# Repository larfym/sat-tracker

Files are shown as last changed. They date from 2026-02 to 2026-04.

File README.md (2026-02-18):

# 🛰️ Satellite Tracker

An ESP32-based automated dual-axis antenna tracking system for Low Earth
Orbit (LEO) satellites, featuring real-time orbital prediction,
closed-loop motor control, and a web-based telemetry interface.

------------------------------------------------------------------------

## 📡 Description

**Satellite Tracker** is an embedded platform designed to automatically
track Low Earth Orbit (LEO) satellites in real time using orbital
prediction algorithms.

The system is powered by an ESP32 microcontroller, which:

-   Computes satellite position using the SGP4 orbital propagation model
-   Synchronizes time and geographic location via GPS
-   Controls a motorized offset dish antenna in azimuth and elevation
-   Provides telemetry and configuration through an integrated web
    interface

The platform is modular, scalable, and suitable for experimentation,
amateur satellite tracking, and engineering research.

------------------------------------------------------------------------

## 🚀 Features

-   Real-time satellite tracking using SGP4 orbit prediction
-   Automatic next-pass prediction
-   GPS-based time and position synchronization
-   Integrated web interface for monitoring and configuration
-   JSON API for remote telemetry access
-   Configurable antenna mechanical offsets
-   Satellite visibility calculation (eclipse / daylight / visible)
-   Scalable and modular firmware architecture
-   Manual and automatic tracking modes
-   Dual-axis mount control (azimuth & elevation)
-   Position feedback using reed switches
-   Motor current monitoring for protection and diagnostics
-   PI-based closed-loop position control

------------------------------------------------------------------------

## 📁 Proyect Structure

    sat-tracker/Firmware
    │
    ├── src/                 # Source code
    ├── include/             # Headers y configurations
    ├── data/                # Web Page (SPIFFS / LittleFS)
    ├── lib/                 # Libs
    ├── platformio.ini       # PlatformIO config.

------------------------------------------------------------------------

## 🔧 Hardware Requirements

-   ESP32 DevKit V1
-   GPS Module
-   Custom Power Interface Board
-   Custom Main Control Board
-   Azimuth and Elevation actuators
-   36V / 5A power supply

------------------------------------------------------------------------

## 💻 Software Dependencies

-   SGP4 -- Satellite orbit prediction\
    https://github.com/Hopperpop/Sgp4-Library

-   ESPAsyncWebServer -- Asynchronous web server\
    https://github.com/me-no-dev/ESPAsyncWebServer

-   TinyGPS++ -- GPS NMEA parsing\
    https://github.com/mikalhart/TinyGPSPlus

-   ArduinoJson -- JSON serialization and parsing\
    https://arduinojson.org/

All dependencies are automatically managed via PlatformIO.

------------------------------------------------------------------------

## 🛠 Building and Installation

1.  Clone this repository:

git clone https://github.com/larfym/sat-tracker.git

2.  Install PlatformIO: https://platformio.org/

3.  Open the Firmware folder in VS Code with the PlatformIO extension.

4.  Build and upload:

platformio run --target uploadfs platformio run --target upload

------------------------------------------------------------------------

## 🌐 Web Interface

To access the web interface:

1.  Connect to the ESP32 WiFi Access Point (Default SSID: SatTracker)
2.  Open your browser and navigate to:

http://tracker.local

From the web interface you can:

-   Configure satellite TLE data
-   Adjust antenna offsets
-   Monitor real-time telemetry
-   Switch between manual and automatic tracking
-   View GPS and system status
-   Monitor next pass prediction

## 📜 License

This project is licensed under the GNU General Public License v3.0 - see [LICENSE](LICENSE) for details.

------------------------------------------------------------------------

🛰 Satellite Tracker -- Embedded autonomous satellite tracking platform.

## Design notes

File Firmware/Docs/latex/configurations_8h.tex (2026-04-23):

\doxysection{include/\+configurations.h File Reference}
\hypertarget{configurations_8h}{}\label{configurations_8h}\index{include/configurations.h@{include/configurations.h}}
{\ttfamily \+\#include $<$Arduino.\+h$>$}\newline
{\ttfamily \+\#include "{}driver/\+gpio.\+h"{}}\newline
\doxysubsubsection*{Macros}
\begin{DoxyCompactItemize}
\item 
\+\#define \doxymbox{\hyperlink{configurations_8h_a56e165627f596c2f42f843ae6571de0e}{PWM\+\_\+\+FREQ\+\_\+\+HZ}}~2500
\begin{DoxyCompactList}\small\item\em PWM frequency for PWM motor speed control (Hz). \end{DoxyCompactList}\end{DoxyCompactItemize}
\begin{Indent}\textbf{ Azimuth Motor Pins (AZ)}\par
{\em Control and measurement pins for the Azimuth motor driver. }\begin{DoxyCompactItemize}
\item 
\+\#define \doxymbox{\hyperlink{configurations_8h_a9ce983ce5b08d7846d8fa31118021b24}{IN1\+\_\+\+AZ\+\_\+\+PIN}}~GPIO\+\_\+\+NUM\+\_\+25
\item 
\+\#define \doxymbox{\hyperlink{configurations_8h_ab18abfaf88f25a5ba352779defd5b333}{EN\+\_\+\+AZ\+\_\+\+PIN}}~GPIO\+\_\+\+NUM\+\_\+12
\item 
\+\#define \doxymbox{\hyperlink{configurations_8h_a9d57a6e7ffc17486374ef9dc813b76f4}{IN2\+\_\+\+AZ\+\_\+\+PIN}}~GPIO\+\_\+\+NUM\+\_\+26
\item 
\+\#define \doxymbox{\hyperlink{configurations_8h_ab1858222d0c9bde8f3a6dc0bfd6c6602}{I\+\_\+\+AZ\+\_\+\+PIN}}~GPIO\+\_\+\+NUM\+\_\+36
\item 
\+\#define \doxymbox{\hyperlink{configurations_8h_a4c9747a154da64ff447148d8d4fa5a20}{I\+\_\+\+AZ\+\_\+\+CHANNEL}}~ADC1\+\_\+\+CHANNEL\+\_\+0
\end{DoxyCompactItemize}
\end{Indent}
\begin{Indent}\textbf{ Elevation Motor Pins (EL)}\par
{\em Control and measurement pins for the Elevation motor driver. }\begin{DoxyCompactItemize}
\item 
\+\#define \doxymbox{\hyperlink{configurations_8h_a2f5dd98516c40e68c6da603ddcab8698}{IN1\+\_\+\+EL\+\_\+\+PIN}}~GPIO\+\_\+\+NUM\+\_\+27
\item 
\+\#define \doxymbox{\hyperlink{configurations_8h_a48348f346a55b4cdd6249e8d8491242d}{EN\+\_\+\+EL\+\_\+\+PIN}}~GPIO\+\_\+\+NUM\+\_\+13
\item 
\+\#define \doxymbox{\hyperlink{configurations_8h_a3c8358b42b349a816f9ef990377fd98b}{IN2\+\_\+\+EL\+\_\+\+PIN}}~GPIO\+\_\+\+NUM\+\_\+14
\item 
\+\#define \doxymbox{\hyperlink{configurations_8h_aad16931d726a00fa1f731f95541eef10}{I\+\_\+\+EL\+\_\+\+PIN}}~GPIO\+\_\+\+NUM\+\_\+39
\item 
\+\#define \doxymbox{\hyperlink{configurations_8h_a879a26029e799249e6786c5890d9f7e1}{I\+\_\+\+EL\+\_\+\+CHANNEL}}~ADC1\+\_\+\+CHANNEL\+\_\+3
\end{DoxyCompactItemize}
\end{Indent}
\begin{Indent}\textbf{ Communication \& Sensor Pins}\par
{\em Pins for external modules (GPS) and reed switch. }\begin{DoxyCompactItemize}
\item 
\+\#define \doxymbox{\hyperlink{configurations_8h_a6f8927970de9eedcbb8f6c14b1d0d6c3}{GPS\+\_\+\+RX\+\_\+\+PIN}}~16
\item 
\+\#define \doxymbox{\hyperlink{configurations_8h_acae14b9c1767cfec367a4b96009c94e5}{GPS\+\_\+\+TX\+\_\+\+PIN}}~17
\item 
\+\#define \doxymbox{\hyperlink{configurations_8h_aa87d687897e717dea73184063e2b3be1}{REED\+\_\+\+AZ\+\_\+\+PIN}}~GPIO\+\_\+\+NUM\+\_\+22
\item 
\+\#define \doxymbox{\hyperlink{configurations_8h_ac623bf5b9b1b5e841f3d5358f5ce36f7}{REED\+\_\+\+EL\+\_\+\+PIN}}~GPIO\+\_\+\+NUM\+\_\+23
\end{DoxyCompactItemize}
\end{Indent}
\begin{Indent}\textbf{ Antenna Mount Dimensions}\par
{\em Geometric parameters of the antenna mount for non-\/linearity compensation.

\begin{DoxyNote}{Note}
See ./\+\+Hardware/\+\+Dimensiones.png for reference. All dimensions are in millimeters. 
\end{DoxyNote}
}\begin{DoxyCompactItemize}
\item 
\+\#define \doxymbox{\hyperlink{configurations_8h_a39a4aef518070719f955536fb18f6636}{A\+\_\+\+ANT}}~50.\+0f
\item 
\+\#define \doxymbox{\hyperlink{configurations_8h_a034c4b2e2cf4a02e546516bea24d038b}{BP\+\_\+\+ANT}}~220.\+11f
\item 
\+\#define \doxymbox{\hyperlink{configurations_8h_a149b23fbb2b8ad13b0ad21dbecd1059a}{C\+\_\+\+ANT}}~276.\+00f
\item 
\+\#define \doxymbox{\hyperlink{configurations_8h_a2ac51fcc017948d66c75b95473b426c4}{D\+\_\+\+ANT}}~145.\+0f
\item 
\+\#define \doxymbox{\hyperlink{configurations_8h_aed5df61912c8c1b1f45d597496d14625}{E\+\_\+\+ANT}}~80.\+0f
\item 
\+\#define \doxymbox{\hyperlink{configurations_8h_accf0d3a1b60705451b9e5a78e37f82c5}{F\+\_\+\+ANT}}~258.\+00f
\end{DoxyCompactItemize}
\end{Indent}
\begin{Indent}\textbf{ Wi\+Fi Configuration}\par
{\em Default parameters for Wi\+Fi access point and m\+DNS service. }\begin{DoxyCompactItemize}
\item 
\+\#define \doxymbox{\hyperlink{configurations_8h_a7ea92631acc3bc41ae5eadc069323267}{DEFAULT\+\_\+\+WIFI\+\_\+\+SSID}}~"{}Tracker\+LARFy\+M"{}
\item 
\+\#define \doxymbox{\hyperlink{configurations_8h_a151690ecdd7d2c7b69586e6df164676c}{DEFAULT\+\_\+\+WIFI\+\_\+\+PASSWORD}}~"{}"{}
\item 
\+\#define \doxymbox{\hyperlink{configurations_8h_af257e2a3e091629829857a2eb8931a7a}{DEFAULT\+\_\+\+SERVER\+\_\+\+PORT}}~80
\item 
\+\#define \doxymbox{\hyperlink{configurations_8h_a2597be4e15dcb4d93d323730f9ac2838}{MDNS\+\_\+\+SERVICE\+\_\+\+NAME}}~"{}Tracker"{}
\end{DoxyCompactItemize}
\end{Indent}
\begin{Indent}\textbf{ Serial Debugging}\par
{\em Default serial monitor parameters. }\begin{DoxyCompactItemize}
\item 
\+\#define \doxymbox{\hyperlink{configurations_8h_a89f82a9d44beaa52b00c7245a50a105c}{SERIAL\+\_\+\+BAUDRATE}}~115200
\end{DoxyCompactItemize}
\end{Indent}
\begin{Indent}\textbf{ GPS Parameters}\par
{\em UART settings and default fallback position/\+time. }\begin{DoxyCompactItemize}
\item 
\+\#define \doxymbox{\hyperlink{configurations_8h_a0276fa67794ae64b565fe0da6db4fc9d}{GPS\+\_\+\+UART}}~1
\item 
\+\#define \doxymbox{\hyperlink{configurations_8h_ac81ef7244c62ee5ea3a9a637a07ac921}{GPS\+\_\+\+BAUDRATE}}~9600
\end{DoxyCompactItemize}
\end{Indent}
\begin{Indent}\textbf{ DC Motor Configuration.}\par
{\em Non Linearity \& Nominal Tension (Saturation) }\begin{DoxyCompactItemize}
\item 
\+\#define \doxymbox{\hyperlink{configurations_8h_a114551a5238cb0c6d988e55ba1d563c1}{M\+\_\+\+V\+\_\+\+NOMINAL}}~36
\item 
\+\#define \doxymbox{\hyperlink{configurations_8h_af612d680313c8e405272d106245d0fe6}{M\+\_\+\+AZ\+\_\+\+V\+\_\+\+TO\+\_\+\+START}}~15.\+5
\item 
\+\#define \doxymbox{\hyperlink{configurations_8h_afd517c26a46c866b3e18cf00c0e9b24b}{M\+\_\+\+EL\+\_\+\+V\+\_\+\+TO\+\_\+\+START}}~9
\item 
\+\#define \doxymbox{\hyperlink{configurations_8h_adf6dcd893480852d7a468e561027c267}{M\+\_\+\+STOP\+\_\+\+DUTY}}~25
\item 
\+\#define \doxymbox{\hyperlink{configurations_8h_ac37c3874949285db365830a0af9ba6f0}{M\+\_\+\+MAX\+\_\+\+DUTY}}~100
\item 
\+\#define \doxymbox{\hyperlink{configurations_8h_aa9fc601eb8b6247f0e9a63ba560190d0}{M\+\_\+\+AZ\+\_\+\+SETTLING\+\_\+\+TIME\+\_\+\+MS}}~65
\item 
\+\#define \doxymbox{\hyperlink{configurations_8h_aa2ff7abced059abb3e126b9e24d8b31a}{M\+\_\+\+EL\+\_\+\+SETTLING\+\_\+\+TIME\+\_\+\+MS}}~100
\item 
\+\#define \doxymbox{\hyperlink{configurations_8h_aa33b361d28f2f88e6bfd400a945594f5}{M\+\_\+\+STOPPED\+\_\+\+CHECK\+\_\+\+INTERVAL\+\_\+\+MS}}~10
\end{DoxyCompactItemize}
\end{Indent}
\begin{Indent}\textbf{ Actuator pulses resolution}\par
{\em Resolution per pulses of reed. }\begin{DoxyCompactItemize}
\item 
\+\#define \doxymbox{\hyperlink{configurations_8h_a618a262e13ca80c7900729cce273a2ac}{AZIMUTH\+\_\+\+RESOLUTION\+\_\+angle}}~0.\+225
\item 
\+\#define \doxymbox{\hyperlink{configurations_8h_a391fdd14353e44f4001f8754e497dbec}{ELEVATION\+\_\+\+RESOLUTION\+\_\+mm}}~0.\+8
\end{DoxyCompactItemize}
\end{Indent}
\begin{Indent}\textbf{ Motor Current Limits}\par
{\em Safety current limits for motor protection. }\begin{DoxyCompactItemize}
\item 
\+\#define \doxymbox{\hyperlink{configurations_8h_a53f290d4e302a2bc20466bea8c913956}{CURRENT\+\_\+\+AZIMUTH\+\_\+\+MAX\+\_\+mA}}~1000.\+0
\item 
\+\#define \doxymbox{\hyperlink{configurations_8h_a23704dd1aa5111b43de738b89232a9e2}{CURRENT\+\_\+\+ELEVATION\+\_\+\+MAX\+\_\+mA}}~1000.\+0
\item 
\+\#define \doxymbox{\hyperlink{configurations_8h_ada73a694caa3cc91084dd186c39d41e1}{CURRENT\+\_\+\+HOMING\+\_\+mA}}~10.\+0
\end{DoxyCompactItemize}
\end{Indent}
\begin{Indent}\textbf{ Timing Parameters}\par
{\em Control-\/loop timing settings. }\begin{DoxyCompactItemize}
\item 
\+\#define \doxymbox{\hyperlink{configurations_8h_ab51c362d04fd48de5e648831613ceb9b}{TIMER\+\_\+\+PREESCALER}}~80
\item 
\+\#define \doxymbox{\hyperlink{configurations_8h_a4b801f5bec6966fa50dbca2c4fd789eb}{DEFAULT\+\_\+\+SAMPLE\+\_\+\+TIME\+\_\+\+US}}~500
\item 
\+\#define \doxymbox{\hyperlink{configurations_8h_a71e747b23aad740159d5c63f2d28f097}{SAMPLE\+\_\+\+TIME\+\_\+\+US}}~500
\item 
\+\#define \doxymbox{\hyperlink{configurations_8h_a048e4fab329b80f602ac97b6aed12979}{SAMPLE\+\_\+\+TIME\+\_\+S}}~(\doxymbox{\hyperlink{configurations_8h_a71e747b23aad740159d5c63f2d28f097}{SAMPLE\+\_\+\+TIME\+\_\+\+US}} /\+ 1000000.\+0)
\item 
\+\#define \doxymbox{\hyperlink{configurations_8h_a3e0f664cc702c0239f5996a93e2e61de}{SAMPLE\+\_\+\+TIME\+\_\+\+SGP4\+\_\+\+MS}}~50
\end{DoxyCompactItemize}
\end{Indent}
\begin{Indent}\textbf{ PID Gains — Azimuth}\par
{\em Gains for the Azimuth axis PI controller. }\begin{DoxyCompactItemize}
\item 
\+\#define \doxymbox{\hyperlink{configurations_8h_aeb86acb27e54b9755fcdac7881be9a67}{KP\+\_\+\+AZIMUTH}}~10.\+0
\item 
\+\#define \doxymbox{\hyperlink{configurations_8h_a84c8a48add65471b6d7a3df86ded588a}{KI\+\_\+\+AZIMUTH}}~1
\end{DoxyCompactItemize}
\end{Indent}
\begin{Indent}\textbf{ PID Gains — Elevation}\par
{\em Gains for the Elevation axis PI controller. }\begin{DoxyCompactItemize}
\item 
\+\#define \doxymbox{\hyperlink{configurations_8h_aa837cea21a670725c8482e7379c50b84}{KP\+\_\+\+ELEVATION}}~7.\+0
\item 
\+\#define \doxymbox{\hyperlink{configurations_8h_a9f3f39cf87464e2b698790a8d22894d4}{KI\+\_\+\+ELEVATION}}~0.\+5
\end{DoxyCompactItemize}
\end{Indent}
\begin{Indent}\textbf{ Soft Limit Positions}\par
{\em Encoder/\+step limits for mechanical range enforcement. }\begin{DoxyCompactItemize}
\item 
\+\#define \doxymbox{\hyperlink{configurations_8h_a9fc5bef92112470db8255986b6ecebcb}{REED\+\_\+\+AZ\+\_\+\+SOFT\+\_\+\+LIMIT\+\_\+\+HIGH}}~1610
\item 
\+\#define \doxymbox{\hyperlink{configurations_8h_a7de64bbb117e66e561add80d7f24374e}{REED\+\_\+\+EL\+\_\+\+SOFT\+\_\+\+LIMIT\+\_\+\+HIGH}}~435
\item 
\+\#define \doxymbox{\hyperlink{configurations_8h_acdaca90d9569b370599f231928e32845}{REED\+\_\+\+AZ\+\_\+\+SOFT\+\_\+\+LIMIT\+\_\+\+LOW}}~-\/5
\item 
\+\#define \doxymbox{\hyperlink{configurations_8h_a08a68068b1a658d3b0e967b799a84100}{REED\+\_\+\+EL\+\_\+\+SOFT\+\_\+\+LIMIT\+\_\+\+LOW}}~-\/5
\end{DoxyCompactItemize}
\end{Indent}
\begin{Indent}\textbf{ Hardware Limit Positions}\par
\begin{DoxyCompactItemize}
\item 
\+\#define \doxymbox{\hyperlink{configurations_8h_ad23baeb01d87433d396f0fe003b8786d}{EL\+\_\+\+MIN\+\_\+\+DEG}}~0
\item 
\+\#define \doxymbox{\hyperlink{configurations_8h_a256d7fdd4d6568904b4d60a6764b3fd1}{EL\+\_\+\+MAX\+\_\+\+DEG}}~90
\item 
\+\#define \doxymbox{\hyperlink{configurations_8h_aa9c6275c5b158a9c5367abcc0a1a51d1}{AZ\+\_\+\+MIN\+\_\+\+DEG}}~0
\item 
\+\#define \doxymbox{\hyperlink{configurations_8h_a9ca2a700dc3c9463ffec3c3e49d919d1}{AZ\+\_\+\+MAX\+\_\+\+DEG}}~340
\end{DoxyCompactItemize}
\end{Indent}
\begin{Indent}\textbf{ Current signal Adaptation}\par
{\em gain \& shunt value }\begin{DoxyCompactItemize}
\item 
\+\#define \doxymbox{\hyperlink{configurations_8h_aa25a725425da550762ed5792cf0a1b65}{SHUNT\+\_\+\+AZ\+\_\+\+OHM}}~0.\+3333333
\item 
\+\#define \doxymbox{\hyperlink{configurations_8h_ab363ea10e9d0da7012f8f6cbdcee7882}{CURRENT\+\_\+\+GAIN\+\_\+\+AZ}}~2.\+11988
\item 
\+\#define \doxymbox{\hyperlink{configurations_8h_afd090c34883b15dab99c6ff746a4af76}{SHUNT\+\_\+\+EL\+\_\+\+OHM}}~0.\+09
\item 
\+\#define \doxymbox{\hyperlink{configurations_8h_a62b33caa3a185c31056a204f70eba631}{CURRENT\+\_\+\+GAIN\+\_\+\+EL}}~7.\+07773
\item 
\+\#define \doxymbox{\hyperlink{configurations_8h_a8a4220fddcc006052f5142591343b76b}{ADC\+\_\+\+MEASURE\+\_\+\+SAMPLES}}~128
\end{DoxyCompactItemize}
\end{Indent}
\begin{Indent}\textbf{ Task Priorities}\par
{\em Priorities for Free\+RTOS tasks (0 = lowest priority). }\begin{DoxyCompactItemize}
\item 
\+\#define \doxymbox{\hyperlink{configurations_8h_a6a03ad7d94899986123153626e22f20e}{TASK\+\_\+\+STOP\+\_\+\+MOTION\+\_\+\+PRIORITY}}~17
\item 
\+\#define \doxymbox{\hyperlink{configurations_8h_a6b00c9b90fcc5568a4740fca93e954b3}{TASK\+\_\+\+HOME\+\_\+\+PRIORITY}}~16
\item 
\+\#define \doxymbox{\hyperlink{configurations_8h_abe8130df0295957593947f186524a786}{TASK\+\_\+\+GPS\+\_\+\+PRIORITY}}~15
\item 
\+\#define \doxymbox{\hyperlink{configurations_8h_af85d4f2634be8dc9a6bd6255f1f8688e}{TASK\+\_\+\+TRACKING\+\_\+\+CALCULATION\+\_\+\+PRIORITY}}~14
\item 
\+\#define \doxymbox{\hyperlink{configurations_8h_a3887054e089a66a41ada671027994436}{TASK\+\_\+\+MOTION\+\_\+\+CONTROL\+\_\+\+PRIORITY}}~14
\item 
\+\#define \doxymbox{\hyperlink{configurations_8h_ac438e71fd931e96cd5d66b3a30630ad9}{TASK\+\_\+\+CURRENT\+\_\+\+MONITOR\+\_\+\+PRIORITY}}~12
\item 
\+\#define \doxymbox{\hyperlink{configurations_8h_a8d137660d77a1310d990d0616a8c2b48}{TASK\+\_\+\+TELEMETRY\+\_\+\+PRIORITY}}~11
\end{DoxyCompactItemize}
\end{Indent}
\begin{Indent}\textbf{ Task Timing Parameters}\par
{\em Timing parameters for Free\+RTOS tasks (in milliseconds). }\begin{DoxyCompactItemize}
\item 
\+\#define \doxymbox{\hyperlink{configurations_8h_a7f179f9e3432a2afae54c63142143cba}{TASK\+\_\+\+LOOP\+\_\+\+DELAY}}~1000
\item 
\+\#define \doxymbox{\hyperlink{configurations_8h_a49fd20d40240fe22eaf939ab4d7f0ead}{TASK\+\_\+\+GPS\+\_\+\+DELAY}}~1000
\item 
\+\#define \doxymbox{\hyperlink{configurations_8h_a21b4e7669d6c855ecc63462be14d163e}{TASK\+\_\+\+CURRENT\+\_\+\+MONITOR\+\_\+\+DELAY}}~3000
\item 
\+\#define \doxymbox{\hyperlink{configurations_8h_a34f3c557893c6a9c133f63f9f3647669}{TASK\+\_\+\+HOME\+\_\+\+CURRENT\+\_\+\+DELAY}}~200
\item 
\+\#define \doxymbox{\hyperlink{configurations_8h_ae38a7f5e2f24d06689d8b847a35e5ccf}{TASK\+\_\+\+TELEMETRY\+\_\+\+DELAY}}~1000
\end{DoxyCompactItemize}
\end{Indent}
\begin{Indent}\textbf{ Task Stack Sizes}\par
{\em Stack sizes for Free\+RTOS tasks (in bytes). }\begin{DoxyCompactItemize}
\item 
\+\#define \doxymbox{\hyperlink{configurations_8h_accbb358028675c83675d8b34c386268d}{MAX\+\_\+\+STACK\+\_\+\+SIZE}}~8192
\item 
\+\#define \doxymbox{\hyperlink{configurations_8h_a214a51a36ae692b76f900157fbd5148d}{MEDIUM\+\_\+\+STACK\+\_\+\+SIZE}}~2048
\item 
\+\#define \doxymbox{\hyperlink{configurations_8h_ac9a8e754ddaa2697e9e675579912a15f}{MIN\+\_\+\+STACK\+\_\+\+SIZE}}~1024
\end{DoxyCompactItemize}
\end{Indent}

\label{doc-define-members}
\Hypertarget{configurations_8h_doc-define-members}
\doxysubsection{Macro Definition Documentation}
\Hypertarget{configurations_8h_a39a4aef518070719f955536fb18f6636}\index{configurations.h@{configurations.h}!A\_ANT@{A\_ANT}}
\index{A\_ANT@{A\_ANT}!configurations.h@{configurations.h}}
\doxysubsubsection{\texorpdfstring{A\_ANT}{A\_ANT}}
{\footnotesize\ttfamily \label{configurations_8h_a39a4aef518070719f955536fb18f6636} 
\+\#define A\+\_\+\+ANT~50.\+0f}

\Hypertarget{configurations_8h_a8a4220fddcc006052f5142591343b76b}\index{configurations.h@{configurations.h}!ADC\_MEASURE\_SAMPLES@{ADC\_MEASURE\_SAMPLES}}
\index{ADC\_MEASURE\_SAMPLES@{ADC\_MEASURE\_SAMPLES}!configurations.h@{configurations.h}}
\doxysubsubsection{\texorpdfstring{ADC\_MEASURE\_SAMPLES}{ADC\_MEASURE\_SAMPLES}}
{\footnotesize\ttfamily \label{configurations_8h_a8a4220fddcc006052f5142591343b76b} 
\+\#define ADC\+\_\+\+MEASURE\+\_\+\+SAMPLES~128}

Number of samples to take for averaging during measurement. \Hypertarget{configurations_8h_a9ca2a700dc3c9463ffec3c3e49d919d1}\index{configurations.h@{configurations.h}!AZ\_MAX\_DEG@{AZ\_MAX\_DEG}}
\index{AZ\_MAX\_DEG@{AZ\_MAX\_DEG}!configurations.h@{configurations.h}}
\doxysubsubsection{\texorpdfstring{AZ\_MAX\_DEG}{AZ\_MAX\_DEG}}
{\footnotesize\ttfamily \label{configurations_8h_a9ca2a700dc3c9463ffec3c3e49d919d1} 
\+\#define AZ\+\_\+\+MAX\+\_\+\+DEG~340}

Upper Set\+Point limit for Azimuth. \Hypertarget{configurations_8h_aa9c6275c5b158a9c5367abcc0a1a51d1}\index{configurations.h@{configurations.h}!AZ\_MIN\_DEG@{AZ\_MIN\_DEG}}
\index{AZ\_MIN\_DEG@{AZ\_MIN\_DEG}!configurations.h@{configurations.h}}
\doxysubsubsection{\texorpdfstring{AZ\_MIN\_DEG}{AZ\_MIN\_DEG}}
{\footnotesize\ttfamily \label{configurations_8h_aa9c6275c5b158a9c5367abcc0a1a51d1} 
\+\#define AZ\+\_\+\+MIN\+\_\+\+DEG~0}

Lower Set\+Point limit for Azimuth. \Hypertarget{configurations_8h_a618a262e13ca80c7900729cce273a2ac}\index{configurations.h@{configurations.h}!AZIMUTH\_RESOLUTION\_angle@{AZIMUTH\_RESOLUTION\_angle}}
\index{AZIMUTH\_RESOLUTION\_angle@{AZIMUTH\_RESOLUTION\_angle}!configurations.h@{configurations.h}}
\doxysubsubsection{\texorpdfstring{AZIMUTH\_RESOLUTION\_angle}{AZIMUTH\_RESOLUTION\_angle}}
{\footnotesize\ttfamily \label{configurations_8h_a618a262e13ca80c7900729cce273a2ac} 
\+\#define AZIMUTH\+\_\+\+RESOLUTION\+\_\+angle~0.\+225}

Degrees per reed pulse for Azimuth. \Hypertarget{configurations_8h_a034c4b2e2cf4a02e546516bea24d038b}\index{configurations.h@{configurations.h}!BP\_ANT@{BP\_ANT}}
\index{BP\_ANT@{BP\_ANT}!configurations.h@{configurations.h}}
\doxysubsubsection{\texorpdfstring{BP\_ANT}{BP\_ANT}}
{\footnotesize\ttfamily \label{configurations_8h_a034c4b2e2cf4a02e546516bea24d038b} 
\+\#define BP\+\_\+\+ANT~220.\+11f}

\Hypertarget{configurations_8h_a149b23fbb2b8ad13b0ad21dbecd1059a}\index{configurations.h@{configurations.h}!C\_ANT@{C\_ANT}}
\index{C\_ANT@{C\_ANT}!configurations.h@{configurations.h}}
\doxysubsubsection{\texorpdfstring{C\_ANT}{C\_ANT}}
{\footnotesize\ttfamily \label{configurations_8h_a149b23fbb2b8ad13b0ad21dbecd1059a} 
\+\#define C\+\_\+\+ANT~276.\+00f}

\Hypertarget{configurations_8h_a53f290d4e302a2bc20466bea8c913956}\index{configurations.h@{configurations.h}!CURRENT\_AZIMUTH\_MAX\_mA@{CURRENT\_AZIMUTH\_MAX\_mA}}
\index{CURRENT\_AZIMUTH\_MAX\_mA@{CURRENT\_AZIMUTH\_MAX\_mA}!configurations.h@{configurations.h}}
\doxysubsubsection{\texorpdfstring{CURRENT\_AZIMUTH\_MAX\_mA}{CURRENT\_AZIMUTH\_MAX\_mA}}
{\footnotesize\ttfamily \label{configurations_8h_a53f290d4e302a2bc20466bea8c913956} 
\+\#define CURRENT\+\_\+\+AZIMUTH\+\_\+\+MAX\+\_\+mA~1000.\+0}

Max DC current for Azimuth motor (mA). \Hypertarget{configurations_8h_a23704dd1aa5111b43de738b89232a9e2}\index{configurations.h@{configurations.h}!CURRENT\_ELEVATION\_MAX\_mA@{CURRENT\_ELEVATION\_MAX\_mA}}
\index{CURRENT\_ELEVATION\_MAX\_mA@{CURRENT\_ELEVATION\_MAX\_mA}!configurations.h@{configurations.h}}
\doxysubsubsection{\texorpdfstring{CURRENT\_ELEVATION\_MAX\_mA}{CURRENT\_ELEVATION\_MAX\_mA}}
{\footnotesize\ttfamily \label{configurations_8h_a23704dd1aa5111b43de738b89232a9e2} 
\+\#define CURRENT\+\_\+\+ELEVATION\+\_\+\+MAX\+\_\+mA~1000.\+0}

Max DC current for Elevation motor (mA). \Hypertarget{configurations_8h_ab363ea10e9d0da7012f8f6cbdcee7882}\index{configurations.h@{configurations.h}!CURRENT\_GAIN\_AZ@{CURRENT\_GAIN\_AZ}}
\index{CURRENT\_GAIN\_AZ@{CURRENT\_GAIN\_AZ}!configurations.h@{configurations.h}}
\doxysubsubsection{\texorpdfstring{CURRENT\_GAIN\_AZ}{CURRENT\_GAIN\_AZ}}
{\footnotesize\ttfamily \label{configurations_8h_ab363ea10e9d0da7012f8f6cbdcee7882} 
\+\#define CURRENT\+\_\+\+GAIN\+\_\+\+AZ~2.\+11988}

Signal Adaptation gain for Azimuth current sensing. \Hypertarget{configurations_8h_a62b33caa3a185c31056a204f70eba631}\index{configurations.h@{configurations.h}!CURRENT\_GAIN\_EL@{CURRENT\_GAIN\_EL}}
\index{CURRENT\_GAIN\_EL@{CURRENT\_GAIN\_EL}!configurations.h@{configurations.h}}
\doxysubsubsection{\texorpdfstring{CURRENT\_GAIN\_EL}{CURRENT\_GAIN\_EL}}
{\footnotesize\ttfamily \label{configurations_8h_a62b33caa3a185c31056a204f70eba631} 
\+\#define CURRENT\+\_\+\+GAIN\+\_\+\+EL~7.\+07773}

Signal Adaptation gain for Elevation current sensing. \Hypertarget{configurations_8h_ada73a694caa3cc91084dd186c39d41e1}\index{configurations.h@{configurations.h}!CURRENT\_HOMING\_mA@{CURRENT\_HOMING\_mA}}
\index{CURRENT\_HOMING\_mA@{CURRENT\_HOMING\_mA}!configurations.h@{configurations.h}}
\doxysubsubsection{\texorpdfstring{CURRENT\_HOMING\_mA}{CURRENT\_HOMING\_mA}}
{\footnotesize\ttfamily \label{configurations_8h_ada73a694caa3cc91084dd186c39d41e1} 
\+\#define CURRENT\+\_\+\+HOMING\+\_\+mA~10.\+0}

Max current for considering the motor turned off. \Hypertarget{configurations_8h_a2ac51fcc017948d66c75b95473b426c4}\index{configurations.h@{configurations.h}!D\_ANT@{D\_ANT}}
\index{D\_ANT@{D\_ANT}!configurations.h@{configurations.h}}
\doxysubsubsection{\texorpdfstring{D\_ANT}{D\_ANT}}
{\footnotesize\ttfamily \label{configurations_8h_a2ac51fcc017948d66c75b95473b426c4} 
\+\#define D\+\_\+\+ANT~145.\+0f}

\Hypertarget{configurations_8h_a4b801f5bec6966fa50dbca2c4fd789eb}\index{configurations.h@{configurations.h}!DEFAULT\_SAMPLE\_TIME\_US@{DEFAULT\_SAMPLE\_TIME\_US}}
\index{DEFAULT\_SAMPLE\_TIME\_US@{DEFAULT\_SAMPLE\_TIME\_US}!configurations.h@{configurations.h}}
\doxysubsubsection{\texorpdfstring{DEFAULT\_SAMPLE\_TIME\_US}{DEFAULT\_SAMPLE\_TIME\_US}}
{\footnotesize\ttfamily \label{configurations_8h_a4b801f5bec6966fa50dbca2c4fd789eb} 
\+\#define DEFAULT\+\_\+\+SAMPLE\+\_\+\+TIME\+\_\+\+US~500}

Default control loop sample time (µs). \Hypertarget{configurations_8h_af257e2a3e091629829857a2eb8931a7a}\index{configurations.h@{configurations.h}!DEFAULT\_SERVER\_PORT@{DEFAULT\_SERVER\_PORT}}
\index{DEFAULT\_SERVER\_PORT@{DEFAULT\_SERVER\_PORT}!configurations.h@{configurations.h}}
\doxysubsubsection{\texorpdfstring{DEFAULT\_SERVER\_PORT}{DEFAULT\_SERVER\_PORT}}
{\footnotesize\ttfamily \label{configurations_8h_af257e2a3e091629829857a2eb8931a7a} 
\+\#define DEFAULT\+\_\+\+SERVER\+\_\+\+PORT~80}

Web server port. \Hypertarget{configurations_8h_a151690ecdd7d2c7b69586e6df164676c}\index{configurations.h@{configurations.h}!DEFAULT\_WIFI\_PASSWORD@{DEFAULT\_WIFI\_PASSWORD}}
\index{DEFAULT\_WIFI\_PASSWORD@{DEFAULT\_WIFI\_PASSWORD}!configurations.h@{configurations.h}}
\doxysubsubsection{\texorpdfstring{DEFAULT\_WIFI\_PASSWORD}{DEFAULT\_WIFI\_PASSWORD}}
{\footnotesize\ttfamily \label{configurations_8h_a151690ecdd7d2c7b69586e6df164676c} 
\+\#define DEFAULT\+\_\+\+WIFI\+\_\+\+PASSWORD~"{}"{}}

Default AP password (empty = open AP). \Hypertarget{configurations_8h_a7ea92631acc3bc41ae5eadc069323267}\index{configurations.h@{configurations.h}!DEFAULT\_WIFI\_SSID@{DEFAULT\_WIFI\_SSID}}
\index{DEFAULT\_WIFI\_SSID@{DEFAULT\_WIFI\_SSID}!configurations.h@{configurations.h}}
\doxysubsubsection{\texorpdfstring{DEFAULT\_WIFI\_SSID}{DEFAULT\_WIFI\_SSID}}
{\footnotesize\ttfamily \label{configurations_8h_a7ea92631acc3bc41ae5eadc069323267} 
\+\#define DEFAULT\+\_\+\+WIFI\+\_\+\+SSID~"{}Tracker\+LARFy\+M"{}}

Default AP SSID. \Hypertarget{configurations_8h_aed5df61912c8c1b1f45d597496d14625}\index{configurations.h@{configurations.h}!E\_ANT@{E\_ANT}}
\index{E\_ANT@{E\_ANT}!configurations.h@{configurations.h}}
\doxysubsubsection{\texorpdfstring{E\_ANT}{E\_ANT}}
{\footnotesize\ttfamily \label{configurations_8h_aed5df61912c8c1b1f45d597496d14625} 
\+\#define E\+\_\+\+ANT~80.\+0f}

\Hypertarget{configurations_8h_a256d7fdd4d6568904b4d60a6764b3fd1}\index{configurations.h@{configurations.h}!EL\_MAX\_DEG@{EL\_MAX\_DEG}}
\index{EL\_MAX\_DEG@{EL\_MAX\_DEG}!configurations.h@{configurations.h}}
\doxysubsubsection{\texorpdfstring{EL\_MAX\_DEG}{EL\_MAX\_DEG}}
{\footnotesize\ttfamily \label{configurations_8h_a256d7fdd4d6568904b4d60a6764b3fd1} 
\+\#define EL\+\_\+\+MAX\+\_\+\+DEG~90}

Upper Set\+Point limit for Elevation. \Hypertarget{configurations_8h_ad23baeb01d87433d396f0fe003b8786d}\index{configurations.h@{configurations.h}!EL\_MIN\_DEG@{EL\_MIN\_DEG}}
\index{EL\_MIN\_DEG@{EL\_MIN\_DEG}!configurations.h@{configurations.h}}
\doxysubsubsection{\texorpdfstring{EL\_MIN\_DEG}{EL\_MIN\_DEG}}
{\footnotesize\ttfamily \label{configurations_8h_ad23baeb01d87433d396f0fe003b8786d} 
\+\#define EL\+\_\+\+MIN\+\_\+\+DEG~0}

Lower Set\+Point limit for Elevation. \Hypertarget{configurations_8h_a391fdd14353e44f4001f8754e497dbec}\index{configurations.h@{configurations.h}!ELEVATION\_RESOLUTION\_mm@{ELEVATION\_RESOLUTION\_mm}}
\index{ELEVATION\_RESOLUTION\_mm@{ELEVATION\_RESOLUTION\_mm}!configurations.h@{configurations.h}}
\doxysubsubsection{\texorpdfstring{ELEVATION\_RESOLUTION\_mm}{ELEVATION\_RESOLUTION\_mm}}
{\footnotesize\ttfamily \label{configurations_8h_a391fdd14353e44f4001f8754e497dbec} 
\+\#define ELEVATION\+\_\+\+RESOLUTION\+\_\+mm~0.\+8}

Millimeters per reed pulse for Elevation. \Hypertarget{configurations_8h_ab18abfaf88f25a5ba352779defd5b333}\index{configurations.h@{configurations.h}!EN\_AZ\_PIN@{EN\_AZ\_PIN}}
\index{EN\_AZ\_PIN@{EN\_AZ\_PIN}!configurations.h@{configurations.h}}
\doxysubsubsection{\texorpdfstring{EN\_AZ\_PIN}{EN\_AZ\_PIN}}
{\footnotesize\ttfamily \label{configurations_8h_ab18abfaf88f25a5ba352779defd5b333} 
\+\#define EN\+\_\+\+AZ\+\_\+\+PIN~GPIO\+\_\+\+NUM\+\_\+12}

Enable/\+\+PWM pin for Azimuth motor. \Hypertarget{configurations_8h_a48348f346a55b4cdd6249e8d8491242d}\index{configurations.h@{configurations.h}!EN\_EL\_PIN@{EN\_EL\_PIN}}
\index{EN\_EL\_PIN@{EN\_EL\_PIN}!configurations.h@{configurations.h}}
\doxysubsubsection{\texorpdfstring{EN\_EL\_PIN}{EN\_EL\_PIN}}
{\footnotesize\ttfamily \label{configurations_8h_a48348f346a55b4cdd6249e8d8491242d} 
\+\#define EN\+\_\+\+EL\+\_\+\+PIN~GPIO\+\_\+\+NUM\+\_\+13}

Enable/\+\+PWM pin for Elevation motor. \Hypertarget{configurations_8h_accf0d3a1b60705451b9e5a78e37f82c5}\index{configurations.h@{configurations.h}!F\_ANT@{F\_ANT}}
\index{F\_ANT@{F\_ANT}!configurations.h@{configurations.h}}
\doxysubsubsection{\texorpdfstring{F\_ANT}{F\_ANT}}
{\footnotesize\ttfamily \label{configurations_8h_accf0d3a1b60705451b9e5a78e37f82c5} 
\+\#define F\+\_\+\+ANT~258.\+00f}

\Hypertarget{configurations_8h_ac81ef7244c62ee5ea3a9a637a07ac921}\index{configurations.h@{configurations.h}!GPS\_BAUDRATE@{GPS\_BAUDRATE}}
\index{GPS\_BAUDRATE@{GPS\_BAUDRATE}!configurations.h@{configurations.h}}
\doxysubsubsection{\texorpdfstring{GPS\_BAUDRATE}{GPS\_BAUDRATE}}
{\footnotesize\ttfamily \label{configurations_8h_ac81ef7244c62ee5ea3a9a637a07ac921} 
\+\#define GPS\+\_\+\+BAUDRATE~9600}

GPS communication baud rate. \Hypertarget{configurations_8h_a6f8927970de9eedcbb8f6c14b1d0d6c3}\index{configurations.h@{configurations.h}!GPS\_RX\_PIN@{GPS\_RX\_PIN}}
\index{GPS\_RX\_PIN@{GPS\_RX\_PIN}!configurations.h@{configurations.h}}
\doxysubsubsection{\texorpdfstring{GPS\_RX\_PIN}{GPS\_RX\_PIN}}
{\footnotesize\ttfamily \label{configurations_8h_a6f8927970de9eedcbb8f6c14b1d0d6c3} 
\+\#define GPS\+\_\+\+RX\+\_\+\+PIN~16}

GPS UART RX pin. \Hypertarget{configurations_8h_acae14b9c1767cfec367a4b96009c94e5}\index{configurations.h@{configurations.h}!GPS\_TX\_PIN@{GPS\_TX\_PIN}}
\index{GPS\_TX\_PIN@{GPS\_TX\_PIN}!configurations.h@{configurations.h}}
\doxysubsubsection{\texorpdfstring{GPS\_TX\_PIN}{GPS\_TX\_PIN}}
{\footnotesize\ttfamily \label{configurations_8h_acae14b9c1767cfec367a4b96009c94e5} 
\+\#define GPS\+\_\+\+TX\+\_\+\+PIN~17}

GPS UART TX pin. \Hypertarget{configurations_8h_a0276fa67794ae64b565fe0da6db4fc9d}\index{configurations.h@{configurations.h}!GPS\_UART@{GPS\_UART}}
\index{GPS\_UART@{GPS\_UART}!configurations.h@{configurations.h}}
\doxysubsubsection{\texorpdfstring{GPS\_UART}{GPS\_UART}}
{\footnotesize\ttfamily \label{configurations_8h_a0276fa67794ae64b565fe0da6db4fc9d} 
\+\#define GPS\+\_\+\+UART~1}

UART index used by GPS. \Hypertarget{configurations_8h_a4c9747a154da64ff447148d8d4fa5a20}\index{configurations.h@{configurations.h}!I\_AZ\_CHANNEL@{I\_AZ\_CHANNEL}}
\index{I\_AZ\_CHANNEL@{I\_AZ\_CHANNEL}!configurations.h@{configurations.h}}
\doxysubsubsection{\texorpdfstring{I\_AZ\_CHANNEL}{I\_AZ\_CHANNEL}}
{\footnotesize\ttfamily \label{configurations_8h_a4c9747a154da64ff447148d8d4fa5a20} 
\+\#define I\+\_\+\+AZ\+\_\+\+CHANNEL~ADC1\+\_\+\+CHANNEL\+\_\+0}

ADC1 channel for Azimuth current sensing. \Hypertarget{configurations_8h_ab1858222d0c9bde8f3a6dc0bfd6c6602}\index{configurations.h@{configurations.h}!I\_AZ\_PIN@{I\_AZ\_PIN}}
\index{I\_AZ\_PIN@{I\_AZ\_PIN}!configurations.h@{configurations.h}}
\doxysubsubsection{\texorpdfstring{I\_AZ\_PIN}{I\_AZ\_PIN}}
{\footnotesize\ttfamily \label{configurations_8h_ab1858222d0c9bde8f3a6dc0bfd6c6602} 
\+\#define I\+\_\+\+AZ\+\_\+\+PIN~GPIO\+\_\+\+NUM\+\_\+36}

Analog pin (VP) for Azimuth current sensing. \Hypertarget{configurations_8h_a879a26029e799249e6786c5890d9f7e1}\index{configurations.h@{configurations.h}!I\_EL\_CHANNEL@{I\_EL\_CHANNEL}}
\index{I\_EL\_CHANNEL@{I\_EL\_CHANNEL}!configurations.h@{configurations.h}}
\doxysubsubsection{\texorpdfstring{I\_EL\_CHANNEL}{I\_EL\_CHANNEL}}
{\footnotesize\ttfamily \label{configurations_8h_a879a26029e799249e6786c5890d9f7e1} 
\+\#define I\+\_\+\+EL\+\_\+\+CHANNEL~ADC1\+\_\+\+CHANNEL\+\_\+3}

ADC1 channel for Elevation current sensing. \Hypertarget{configurations_8h_aad16931d726a00fa1f731f95541eef10}\index{configurations.h@{configurations.h}!I\_EL\_PIN@{I\_EL\_PIN}}
\index{I\_EL\_PIN@{I\_EL\_PIN}!configurations.h@{configurations.h}}
\doxysubsubsection{\texorpdfstring{I\_EL\_PIN}{I\_EL\_PIN}}
{\footnotesize\ttfamily \label{configurations_8h_aad16931d726a00fa1f731f95541eef10} 
\+\#define I\+\_\+\+EL\+\_\+\+PIN~GPIO\+\_\+\+NUM\+\_\+39}

Analog pin (VN) for Elevation current sensing. \Hypertarget{configurations_8h_a9ce983ce5b08d7846d8fa31118021b24}\index{configurations.h@{configurations.h}!IN1\_AZ\_PIN@{IN1\_AZ\_PIN}}
\index{IN1\_AZ\_PIN@{IN1\_AZ\_PIN}!configurations.h@{configurations.h}}
\doxysubsubsection{\texorpdfstring{IN1\_AZ\_PIN}{IN1\_AZ\_PIN}}
{\footnotesize\ttfamily \label{configurations_8h_a9ce983ce5b08d7846d8fa31118021b24} 
\+\#define IN1\+\_\+\+AZ\+\_\+\+PIN~GPIO\+\_\+\+NUM\+\_\+25}

Input pin 1 of the Azimuth motor driver. \Hypertarget{configurations_8h_a2f5dd98516c40e68c6da603ddcab8698}\index{configurations.h@{configurations.h}!IN1\_EL\_PIN@{IN1\_EL\_PIN}}
\index{IN1\_EL\_PIN@{IN1\_EL\_PIN}!configurations.h@{configurations.h}}
\doxysubsubsection{\texorpdfstring{IN1\_EL\_PIN}{IN1\_EL\_PIN}}
{\footnotesize\ttfamily \label{configurations_8h_a2f5dd98516c40e68c6da603ddcab8698} 
\+\#define IN1\+\_\+\+EL\+\_\+\+PIN~GPIO\+\_\+\+NUM\+\_\+27}

Input pin 1 of the Elevation motor driver. \Hypertarget{configurations_8h_a9d57a6e7ffc17486374ef9dc813b76f4}\index{configurations.h@{configurations.h}!IN2\_AZ\_PIN@{IN2\_AZ\_PIN}}
\index{IN2\_AZ\_PIN@{IN2\_AZ\_PIN}!configurations.h@{configurations.h}}
\doxysubsubsection{\texorpdfstring{IN2\_AZ\_PIN}{IN2\_AZ\_PIN}}
{\footnotesize\ttfamily \label{configurations_8h_a9d57a6e7ffc17486374ef9dc813b76f4} 
\+\#define IN2\+\_\+\+AZ\+\_\+\+PIN~GPIO\+\_\+\+NUM\+\_\+26}

Input pin 2 of the Azimuth motor driver. \Hypertarget{configurations_8h_a3c8358b42b349a816f9ef990377fd98b}\index{configurations.h@{configurations.h}!IN2\_EL\_PIN@{IN2\_EL\_PIN}}
\index{IN2\_EL\_PIN@{IN2\_EL\_PIN}!configurations.h@{configurations.h}}
\doxysubsubsection{\texorpdfstring{IN2\_EL\_PIN}{IN2\_EL\_PIN}}
{\footnotesize\ttfamily \label{configurations_8h_a3c8358b42b349a816f9ef990377fd98b} 
\+\#define IN2\+\_\+\+EL\+\_\+\+PIN~GPIO\+\_\+\+NUM\+\_\+14}

Input pin 2 of the Elevation motor driver. \Hypertarget{configurations_8h_a84c8a48add65471b6d7a3df86ded588a}\index{configurations.h@{configurations.h}!KI\_AZIMUTH@{KI\_AZIMUTH}}
\index{KI\_AZIMUTH@{KI\_AZIMUTH}!configurations.h@{configurations.h}}
\doxysubsubsection{\texorpdfstring{KI\_AZIMUTH}{KI\_AZIMUTH}}
{\footnotesize\ttfamily \label{configurations_8h_a84c8a48add65471b6d7a3df86ded588a} 
\+\#define KI\+\_\+\+AZIMUTH~1}

Integral gain (AZ). 0.\+1 \Hypertarget{configurations_8h_a9f3f39cf87464e2b698790a8d22894d4}\index{configurations.h@{configurations.h}!KI\_ELEVATION@{KI\_ELEVATION}}
\index{KI\_ELEVATION@{KI\_ELEVATION}!configurations.h@{configurations.h}}
\doxysubsubsection{\texorpdfstring{KI\_ELEVATION}{KI\_ELEVATION}}
{\footnotesize\ttfamily \label{configurations_8h_a9f3f39cf87464e2b698790a8d22894d4} 
\+\#define KI\+\_\+\+ELEVATION~0.\+5}

Integral gain (EL). 0.\+001 \Hypertarget{configurations_8h_aeb86acb27e54b9755fcdac7881be9a67}\index{configurations.h@{configurations.h}!KP\_AZIMUTH@{KP\_AZIMUTH}}
\index{KP\_AZIMUTH@{KP\_AZIMUTH}!configurations.h@{configurations.h}}
\doxysubsubsection{\texorpdfstring{KP\_AZIMUTH}{KP\_AZIMUTH}}
{\footnotesize\ttfamily \label{configurations_8h_aeb86acb27e54b9755fcdac7881be9a67} 
\+\#define KP\+\_\+\+AZIMUTH~10.\+0}

Proportional gain (AZ). 10 \Hypertarget{configurations_8h_aa837cea21a670725c8482e7379c50b84}\index{configurations.h@{configurations.h}!KP\_ELEVATION@{KP\_ELEVATION}}
\index{KP\_ELEVATION@{KP\_ELEVATION}!configurations.h@{configurations.h}}
\doxysubsubsection{\texorpdfstring{KP\_ELEVATION}{KP\_ELEVATION}}
{\footnotesize\ttfamily \label{configurations_8h_aa837cea21a670725c8482e7379c50b84} 
\+\#define KP\+\_\+\+ELEVATION~7.\+0}

Proportional gain (EL). 5 \Hypertarget{configurations_8h_aa9fc601eb8b6247f0e9a63ba560190d0}\index{configurations.h@{configurations.h}!M\_AZ\_SETTLING\_TIME\_MS@{M\_AZ\_SETTLING\_TIME\_MS}}
\index{M\_AZ\_SETTLING\_TIME\_MS@{M\_AZ\_SETTLING\_TIME\_MS}!configurations.h@{configurations.h}}
\doxysubsubsection{\texorpdfstring{M\_AZ\_SETTLING\_TIME\_MS}{M\_AZ\_SETTLING\_TIME\_MS}}
{\footnotesize\ttfamily \label{configurations_8h_aa9fc601eb8b6247f0e9a63ba560190d0} 
\+\#define M\+\_\+\+AZ\+\_\+\+SETTLING\+\_\+\+TIME\+\_\+\+MS~65}

Settling time for Azimuth motor (ms). \Hypertarget{configurations_8h_af612d680313c8e405272d106245d0fe6}\index{configurations.h@{configurations.h}!M\_AZ\_V\_TO\_START@{M\_AZ\_V\_TO\_START}}
\index{M\_AZ\_V\_TO\_START@{M\_AZ\_V\_TO\_START}!configurations.h@{configurations.h}}
\doxysubsubsection{\texorpdfstring{M\_AZ\_V\_TO\_START}{M\_AZ\_V\_TO\_START}}
{\footnotesize\ttfamily \label{configurations_8h_af612d680313c8e405272d106245d0fe6} 
\+\#define M\+\_\+\+AZ\+\_\+\+V\+\_\+\+TO\+\_\+\+START~15.\+5}

Minimum voltage to overcome static friction (Azimuth). Note:\+ Values from PWM modulation \Hypertarget{configurations_8h_aa2ff7abced059abb3e126b9e24d8b31a}\index{configurations.h@{configurations.h}!M\_EL\_SETTLING\_TIME\_MS@{M\_EL\_SETTLING\_TIME\_MS}}
\index{M\_EL\_SETTLING\_TIME\_MS@{M\_EL\_SETTLING\_TIME\_MS}!configurations.h@{configurations.h}}
\doxysubsubsection{\texorpdfstring{M\_EL\_SETTLING\_TIME\_MS}{M\_EL\_SETTLING\_TIME\_MS}}
{\footnotesize\ttfamily \label{configurations_8h_aa2ff7abced059abb3e126b9e24d8b31a} 
\+\#define M\+\_\+\+EL\+\_\+\+SETTLING\+\_\+\+TIME\+\_\+\+MS~100}

Settling time for Elevation motor (ms). \Hypertarget{configurations_8h_afd517c26a46c866b3e18cf00c0e9b24b}\index{configurations.h@{configurations.h}!M\_EL\_V\_TO\_START@{M\_EL\_V\_TO\_START}}
\index{M\_EL\_V\_TO\_START@{M\_EL\_V\_TO\_START}!configurations.h@{configurations.h}}
\doxysubsubsection{\texorpdfstring{M\_EL\_V\_TO\_START}{M\_EL\_V\_TO\_START}}
{\footnotesize\ttfamily \label{configurations_8h_afd517c26a46c866b3e18cf00c0e9b24b} 
\+\#define M\+\_\+\+EL\+\_\+\+V\+\_\+\+TO\+\_\+\+START~9}

Minimum voltage to overcome static friction (Elevation). Note:\+ Values from PWM modulation \Hypertarget{configurations_8h_ac37c3874949285db365830a0af9ba6f0}\index{configurations.h@{configurations.h}!M\_MAX\_DUTY@{M\_MAX\_DUTY}}
\index{M\_MAX\_DUTY@{M\_MAX\_DUTY}!configurations.h@{configurations.h}}
\doxysubsubsection{\texorpdfstring{M\_MAX\_DUTY}{M\_MAX\_DUTY}}
{\footnotesize\ttfamily \label{configurations_8h_ac37c3874949285db365830a0af9ba6f0} 
\+\#define M\+\_\+\+MAX\+\_\+\+DUTY~100}

Maximum duty cycle for motors (0-\/100\%). \Hypertarget{configurations_8h_adf6dcd893480852d7a468e561027c267}\index{configurations.h@{configurations.h}!M\_STOP\_DUTY@{M\_STOP\_DUTY}}
\index{M\_STOP\_DUTY@{M\_STOP\_DUTY}!configurations.h@{configurations.h}}
\doxysubsubsection{\texorpdfstring{M\_STOP\_DUTY}{M\_STOP\_DUTY}}
{\footnotesize\ttfamily \label{configurations_8h_adf6dcd893480852d7a468e561027c267} 
\+\#define M\+\_\+\+STOP\+\_\+\+DUTY~25}

Duty cycle to apply for stopping the motors (0-\/100\%). \Hypertarget{configurations_8h_aa33b361d28f2f88e6bfd400a945594f5}\index{configurations.h@{configurations.h}!M\_STOPPED\_CHECK\_INTERVAL\_MS@{M\_STOPPED\_CHECK\_INTERVAL\_MS}}
\index{M\_STOPPED\_CHECK\_INTERVAL\_MS@{M\_STOPPED\_CHECK\_INTERVAL\_MS}!configurations.h@{configurations.h}}
\doxysubsubsection{\texorpdfstring{M\_STOPPED\_CHECK\_INTERVAL\_MS}{M\_STOPPED\_CHECK\_INTERVAL\_MS}}
{\footnotesize\ttfamily \label{configurations_8h_aa33b361d28f2f88e6bfd400a945594f5} 
\+\#define M\+\_\+\+STOPPED\+\_\+\+CHECK\+\_\+\+INTERVAL\+\_\+\+MS~10}

Checking time interval (ms) \Hypertarget{configurations_8h_a114551a5238cb0c6d988e55ba1d563c1}\index{configurations.h@{configurations.h}!M\_V\_NOMINAL@{M\_V\_NOMINAL}}
\index{M\_V\_NOMINAL@{M\_V\_NOMINAL}!configurations.h@{configurations.h}}
\doxysubsubsection{\texorpdfstring{M\_V\_NOMINAL}{M\_V\_NOMINAL}}
{\footnotesize\ttfamily \label{configurations_8h_a114551a5238cb0c6d988e55ba1d563c1} 
\+\#define M\+\_\+\+V\+\_\+\+NOMINAL~36}

Nominal voltage for motors (V). \Hypertarget{configurations_8h_accbb358028675c83675d8b34c386268d}\index{configurations.h@{configurations.h}!MAX\_STACK\_SIZE@{MAX\_STACK\_SIZE}}
\index{MAX\_STACK\_SIZE@{MAX\_STACK\_SIZE}!configurations.h@{configurations.h}}
\doxysubsubsection{\texorpdfstring{MAX\_STACK\_SIZE}{MAX\_STACK\_SIZE}}
{\footnotesize\ttfamily \label{configurations_8h_accbb358028675c83675d8b34c386268d} 
\+\#define MAX\+\_\+\+STACK\+\_\+\+SIZE~8192}

Maximum stack size for Free\+RTOS tasks (bytes). \Hypertarget{configurations_8h_a2597be4e15dcb4d93d323730f9ac2838}\index{configurations.h@{configurations.h}!MDNS\_SERVICE\_NAME@{MDNS\_SERVICE\_NAME}}
\index{MDNS\_SERVICE\_NAME@{MDNS\_SERVICE\_NAME}!configurations.h@{configurations.h}}
\doxysubsubsection{\texorpdfstring{MDNS\_SERVICE\_NAME}{MDNS\_SERVICE\_NAME}}
{\footnotesize\ttfamily \label{configurations_8h_a2597be4e15dcb4d93d323730f9ac2838} 
\+\#define MDNS\+\_\+\+SERVICE\+\_\+\+NAME~"{}Tracker"{}}

m\+DNS hostname. \Hypertarget{configurations_8h_a214a51a36ae692b76f900157fbd5148d}\index{configurations.h@{configurations.h}!MEDIUM\_STACK\_SIZE@{MEDIUM\_STACK\_SIZE}}
\index{MEDIUM\_STACK\_SIZE@{MEDIUM\_STACK\_SIZE}!configurations.h@{configurations.h}}
\doxysubsubsection{\texorpdfstring{MEDIUM\_STACK\_SIZE}{MEDIUM\_STACK\_SIZE}}
{\footnotesize\ttfamily \label{configurations_8h_a214a51a36ae692b76f900157fbd5148d} 
\+\#define MEDIUM\+\_\+\+STACK\+\_\+\+SIZE~2048}

Medium stack size for Free\+RTOS tasks (bytes). \Hypertarget{configurations_8h_ac9a8e754ddaa2697e9e675579912a15f}\index{configurations.h@{configurations.h}!MIN\_STACK\_SIZE@{MIN\_STACK\_SIZE}}
\index{MIN\_STACK\_SIZE@{MIN\_STACK\_SIZE}!configurations.h@{configurations.h}}
\doxysubsubsection{\texorpdfstring{MIN\_STACK\_SIZE}{MIN\_STACK\_SIZE}}
{\footnotesize\ttfamily \label{configurations_8h_ac9a8e754ddaa2697e9e675579912a15f} 
\+\#define MIN\+\_\+\+STACK\+\_\+\+SIZE~1024}

Minimum stack size for Free\+RTOS tasks (bytes). \Hypertarget{configurations_8h_a56e165627f596c2f42f843ae6571de0e}\index{configurations.h@{configurations.h}!PWM\_FREQ\_HZ@{PWM\_FREQ\_HZ}}
\index{PWM\_FREQ\_HZ@{PWM\_FREQ\_HZ}!configurations.h@{configurations.h}}
\doxysubsubsection{\texorpdfstring{PWM\_FREQ\_HZ}{PWM\_FREQ\_HZ}}
{\footnotesize\ttfamily \label{configurations_8h_a56e165627f596c2f42f843ae6571de0e} 
\+\#define PWM\+\_\+\+FREQ\+\_\+\+HZ~2500}

PWM frequency for PWM motor speed control (Hz). 

\Hypertarget{configurations_8h_aa87d687897e717dea73184063e2b3be1}\index{configurations.h@{configurations.h}!REED\_AZ\_PIN@{REED\_AZ\_PIN}}
\index{REED\_AZ\_PIN@{REED\_AZ\_PIN}!configurations.h@{configurations.h}}
\doxysubsubsection{\texorpdfstring{REED\_AZ\_PIN}{REED\_AZ\_PIN}}
{\footnotesize\ttfamily \label{configurations_8h_aa87d687897e717dea73184063e2b3be1} 
\+\#define REED\+\_\+\+AZ\+\_\+\+PIN~GPIO\+\_\+\+NUM\+\_\+22}

Reed switch for Azimuth limit detection. \Hypertarget{configurations_8h_a9fc5bef92112470db8255986b6ecebcb}\index{configurations.h@{configurations.h}!REED\_AZ\_SOFT\_LIMIT\_HIGH@{REED\_AZ\_SOFT\_LIMIT\_HIGH}}
\index{REED\_AZ\_SOFT\_LIMIT\_HIGH@{REED\_AZ\_SOFT\_LIMIT\_HIGH}!configurations.h@{configurations.h}}
\doxysubsubsection{\texorpdfstring{REED\_AZ\_SOFT\_LIMIT\_HIGH}{REED\_AZ\_SOFT\_LIMIT\_HIGH}}
{\footnotesize\ttfamily \label{configurations_8h_a9fc5bef92112470db8255986b6ecebcb} 
\+\#define REED\+\_\+\+AZ\+\_\+\+SOFT\+\_\+\+LIMIT\+\_\+\+HIGH~1610}

Upper soft limit for Azimuth. (362.\+25° máx) \Hypertarget{configurations_8h_acdaca90d9569b370599f231928e32845}\index{configurations.h@{configurations.h}!REED\_AZ\_SOFT\_LIMIT\_LOW@{REED\_AZ\_SOFT\_LIMIT\_LOW}}
\index{REED\_AZ\_SOFT\_LIMIT\_LOW@{REED\_AZ\_SOFT\_LIMIT\_LOW}!configurations.h@{configurations.h}}
\doxysubsubsection{\texorpdfstring{REED\_AZ\_SOFT\_LIMIT\_LOW}{REED\_AZ\_SOFT\_LIMIT\_LOW}}
{\footnotesize\ttfamily \label{configurations_8h_acdaca90d9569b370599f231928e32845} 
\+\#define REED\+\_\+\+AZ\+\_\+\+SOFT\+\_\+\+LIMIT\+\_\+\+LOW~-\/5}

Lower soft limit for Azimuth \Hypertarget{configurations_8h_ac623bf5b9b1b5e841f3d5358f5ce36f7}\index{configurations.h@{configurations.h}!REED\_EL\_PIN@{REED\_EL\_PIN}}
\index{REED\_EL\_PIN@{REED\_EL\_PIN}!configurations.h@{configurations.h}}
\doxysubsubsection{\texorpdfstring{REED\_EL\_PIN}{REED\_EL\_PIN}}
{\footnotesize\ttfamily \label{configurations_8h_ac623bf5b9b1b5e841f3d5358f5ce36f7} 
\+\#define REED\+\_\+\+EL\+\_\+\+PIN~GPIO\+\_\+\+NUM\+\_\+23}

Reed switch for Elevation limit detection. \Hypertarget{configurations_8h_a7de64bbb117e66e561add80d7f24374e}\index{configurations.h@{configurations.h}!REED\_EL\_SOFT\_LIMIT\_HIGH@{REED\_EL\_SOFT\_LIMIT\_HIGH}}
\index{REED\_EL\_SOFT\_LIMIT\_HIGH@{REED\_EL\_SOFT\_LIMIT\_HIGH}!configurations.h@{configurations.h}}
\doxysubsubsection{\texorpdfstring{REED\_EL\_SOFT\_LIMIT\_HIGH}{REED\_EL\_SOFT\_LIMIT\_HIGH}}
{\footnotesize\ttfamily \label{configurations_8h_a7de64bbb117e66e561add80d7f24374e} 
\+\#define REED\+\_\+\+EL\+\_\+\+SOFT\+\_\+\+LIMIT\+\_\+\+HIGH~435}

Upper soft limit for Elevation. (348mm máx) \Hypertarget{configurations_8h_a08a68068b1a658d3b0e967b799a84100}\index{configurations.h@{configurations.h}!REED\_EL\_SOFT\_LIMIT\_LOW@{REED\_EL\_SOFT\_LIMIT\_LOW}}
\index{REED\_EL\_SOFT\_LIMIT\_LOW@{REED\_EL\_SOFT\_LIMIT\_LOW}!configurations.h@{configurations.h}}
\doxysubsubsection{\texorpdfstring{REED\_EL\_SOFT\_LIMIT\_LOW}{REED\_EL\_SOFT\_LIMIT\_LOW}}
{\footnotesize\ttfamily \label{configurations_8h_a08a68068b1a658d3b0e967b799a84100} 
\+\#define REED\+\_\+\+EL\+\_\+\+SOFT\+\_\+\+LIMIT\+\_\+\+LOW~-\/5}

Lower soft limit for Elevation \Hypertarget{configurations_8h_a048e4fab329b80f602ac97b6aed12979}\index{configurations.h@{configurations.h}!SAMPLE\_TIME\_S@{SAMPLE\_TIME\_S}}
\index{SAMPLE\_TIME\_S@{SAMPLE\_TIME\_S}!configurations.h@{configurations.h}}
\doxysubsubsection{\texorpdfstring{SAMPLE\_TIME\_S}{SAMPLE\_TIME\_S}}
{\footnotesize\ttfamily \label{configurations_8h_a048e4fab329b80f602ac97b6aed12979} 
\+\#define SAMPLE\+\_\+\+TIME\+\_\+S~(\doxymbox{\hyperlink{configurations_8h_a71e747b23aad740159d5c63f2d28f097}{SAMPLE\+\_\+\+TIME\+\_\+\+US}} /\+ 1000000.\+0)}

Control loop sample time (s). \Hypertarget{configurations_8h_a3e0f664cc702c0239f5996a93e2e61de}\index{configurations.h@{configurations.h}!SAMPLE\_TIME\_SGP4\_MS@{SAMPLE\_TIME\_SGP4\_MS}}
\index{SAMPLE\_TIME\_SGP4\_MS@{SAMPLE\_TIME\_SGP4\_MS}!configurations.h@{configurations.h}}
\doxysubsubsection{\texorpdfstring{SAMPLE\_TIME\_SGP4\_MS}{SAMPLE\_TIME\_SGP4\_MS}}
{\footnotesize\ttfamily \label{configurations_8h_a3e0f664cc702c0239f5996a93e2e61de} 
\+\#define SAMPLE\+\_\+\+TIME\+\_\+\+SGP4\+\_\+\+MS~50}

SGP4 Trayectory estimation time (ms). \Hypertarget{configurations_8h_a71e747b23aad740159d5c63f2d28f097}\index{configurations.h@{configurations.h}!SAMPLE\_TIME\_US@{SAMPLE\_TIME\_US}}
\index{SAMPLE\_TIME\_US@{SAMPLE\_TIME\_US}!configurations.h@{configurations.h}}
\doxysubsubsection{\texorpdfstring{SAMPLE\_TIME\_US}{SAMPLE\_TIME\_US}}
{\footnotesize\ttfamily \label{configurations_8h_a71e747b23aad740159d5c63f2d28f097} 
\+\#define SAMPLE\+\_\+\+TIME\+\_\+\+US~500}

Control loop sample time (µs). \Hypertarget{configurations_8h_a89f82a9d44beaa52b00c7245a50a105c}\index{configurations.h@{configurations.h}!SERIAL\_BAUDRATE@{SERIAL\_BAUDRATE}}
\index{SERIAL\_BAUDRATE@{SERIAL\_BAUDRATE}!configurations.h@{configurations.h}}
\doxysubsubsection{\texorpdfstring{SERIAL\_BAUDRATE}{SERIAL\_BAUDRATE}}
{\footnotesize\ttfamily \label{configurations_8h_a89f82a9d44beaa52b00c7245a50a105c} 
\+\#define SERIAL\+\_\+\+BAUDRATE~115200}

Baud rate for USB serial monitor. \Hypertarget{configurations_8h_aa25a725425da550762ed5792cf0a1b65}\index{configurations.h@{configurations.h}!SHUNT\_AZ\_OHM@{SHUNT\_AZ\_OHM}}
\index{SHUNT\_AZ\_OHM@{SHUNT\_AZ\_OHM}!configurations.h@{configurations.h}}
\doxysubsubsection{\texorpdfstring{SHUNT\_AZ\_OHM}{SHUNT\_AZ\_OHM}}
{\footnotesize\ttfamily \label{configurations_8h_aa25a725425da550762ed5792cf0a1b65} 
\+\#define SHUNT\+\_\+\+AZ\+\_\+\+OHM~0.\+3333333}

Shunt resistor value for Azimuth current sensing (Ohms). \Hypertarget{configurations_8h_afd090c34883b15dab99c6ff746a4af76}\index{configurations.h@{configurations.h}!SHUNT\_EL\_OHM@{SHUNT\_EL\_OHM}}
\index{SHUNT\_EL\_OHM@{SHUNT\_EL\_OHM}!configurations.h@{configurations.h}}
\doxysubsubsection{\texorpdfstring{SHUNT\_EL\_OHM}{SHUNT\_EL\_OHM}}
{\footnotesize\ttfamily \label{configurations_8h_afd090c34883b15dab99c6ff746a4af76} 
\+\#define SHUNT\+\_\+\+EL\+\_\+\+OHM~0.\+09}

Shunt resistor value for Elevation current sensing (Ohms). \Hypertarget{configurations_8h_a21b4e7669d6c855ecc63462be14d163e}\index{configurations.h@{configurations.h}!TASK\_CURRENT\_MONITOR\_DELAY@{TASK\_CURRENT\_MONITOR\_DELAY}}
\index{TASK\_CURRENT\_MONITOR\_DELAY@{TASK\_CURRENT\_MONITOR\_DELAY}!configurations.h@{configurations.h}}
\doxysubsubsection{\texorpdfstring{TASK\_CURRENT\_MONITOR\_DELAY}{TASK\_CURRENT\_MONITOR\_DELAY}}
{\footnotesize\ttfamily \label{configurations_8h_a21b4e7669d6c855ecc63462be14d163e} 
\+\#define TASK\+\_\+\+CURRENT\+\_\+\+MONITOR\+\_\+\+DELAY~3000}

Delay for Current Monitor task (ms). \Hypertarget{configurations_8h_ac438e71fd931e96cd5d66b3a30630ad9}\index{configurations.h@{configurations.h}!TASK\_CURRENT\_MONITOR\_PRIORITY@{TASK\_CURRENT\_MONITOR\_PRIORITY}}
\index{TASK\_CURRENT\_MONITOR\_PRIORITY@{TASK\_CURRENT\_MONITOR\_PRIORITY}!configurations.h@{configurations.h}}
\doxysubsubsection{\texorpdfstring{TASK\_CURRENT\_MONITOR\_PRIORITY}{TASK\_CURRENT\_MONITOR\_PRIORITY}}
{\footnotesize\ttfamily \label{configurations_8h_ac438e71fd931e96cd5d66b3a30630ad9} 
\+\#define TASK\+\_\+\+CURRENT\+\_\+\+MONITOR\+\_\+\+PRIORITY~12}

\Hypertarget{configurations_8h_a49fd20d40240fe22eaf939ab4d7f0ead}\index{configurations.h@{configurations.h}!TASK\_GPS\_DELAY@{TASK\_GPS\_DELAY}}
\index{TASK\_GPS\_DELAY@{TASK\_GPS\_DELAY}!configurations.h@{configurations.h}}
\doxysubsubsection{\texorpdfstring{TASK\_GPS\_DELAY}{TASK\_GPS\_DELAY}}
{\footnotesize\ttfamily \label{configurations_8h_a49fd20d40240fe22eaf939ab4d7f0ead} 
\+\#define TASK\+\_\+\+GPS\+\_\+\+DELAY~1000}

Delay for GPS task (ms). \Hypertarget{configurations_8h_abe8130df0295957593947f186524a786}\index{configurations.h@{configurations.h}!TASK\_GPS\_PRIORITY@{TASK\_GPS\_PRIORITY}}
\index{TASK\_GPS\_PRIORITY@{TASK\_GPS\_PRIORITY}!configurations.h@{configurations.h}}
\doxysubsubsection{\texorpdfstring{TASK\_GPS\_PRIORITY}{TASK\_GPS\_PRIORITY}}
{\footnotesize\ttfamily \label{configurations_8h_abe8130df0295957593947f186524a786} 
\+\#define TASK\+\_\+\+GPS\+\_\+\+PRIORITY~15}

\Hypertarget{configurations_8h_a34f3c557893c6a9c133f63f9f3647669}\index{configurations.h@{configurations.h}!TASK\_HOME\_CURRENT\_DELAY@{TASK\_HOME\_CURRENT\_DELAY}}
\index{TASK\_HOME\_CURRENT\_DELAY@{TASK\_HOME\_CURRENT\_DELAY}!configurations.h@{configurations.h}}
\doxysubsubsection{\texorpdfstring{TASK\_HOME\_CURRENT\_DELAY}{TASK\_HOME\_CURRENT\_DELAY}}
{\footnotesize\ttfamily \label{configurations_8h_a34f3c557893c6a9c133f63f9f3647669} 
\+\#define TASK\+\_\+\+HOME\+\_\+\+CURRENT\+\_\+\+DELAY~200}

Delay for Home Current task (ms). \Hypertarget{configurations_8h_a6b00c9b90fcc5568a4740fca93e954b3}\index{configurations.h@{configurations.h}!TASK\_HOME\_PRIORITY@{TASK\_HOME\_PRIORITY}}
\index{TASK\_HOME\_PRIORITY@{TASK\_HOME\_PRIORITY}!configurations.h@{configurations.h}}
\doxysubsubsection{\texorpdfstring{TASK\_HOME\_PRIORITY}{TASK\_HOME\_PRIORITY}}
{\footnotesize\ttfamily \label{configurations_8h_a6b00c9b90fcc5568a4740fca93e954b3} 
\+\#define TASK\+\_\+\+HOME\+\_\+\+PRIORITY~16}

\Hypertarget{configurations_8h_a7f179f9e3432a2afae54c63142143cba}\index{configurations.h@{configurations.h}!TASK\_LOOP\_DELAY@{TASK\_LOOP\_DELAY}}
\index{TASK\_LOOP\_DELAY@{TASK\_LOOP\_DELAY}!configurations.h@{configurations.h}}
\doxysubsubsection{\texorpdfstring{TASK\_LOOP\_DELAY}{TASK\_LOOP\_DELAY}}
{\footnotesize\ttfamily \label{configurations_8h_a7f179f9e3432a2afae54c63142143cba} 
\+\#define TASK\+\_\+\+LOOP\+\_\+\+DELAY~1000}

Delay for main loop task (ms). \Hypertarget{configurations_8h_a3887054e089a66a41ada671027994436}\index{configurations.h@{configurations.h}!TASK\_MOTION\_CONTROL\_PRIORITY@{TASK\_MOTION\_CONTROL\_PRIORITY}}
\index{TASK\_MOTION\_CONTROL\_PRIORITY@{TASK\_MOTION\_CONTROL\_PRIORITY}!configurations.h@{configurations.h}}
\doxysubsubsection{\texorpdfstring{TASK\_MOTION\_CONTROL\_PRIORITY}{TASK\_MOTION\_CONTROL\_PRIORITY}}
{\footnotesize\ttfamily \label{configurations_8h_a3887054e089a66a41ada671027994436} 
\+\#define TASK\+\_\+\+MOTION\+\_\+\+CONTROL\+\_\+\+PRIORITY~14}

\Hypertarget{configurations_8h_a6a03ad7d94899986123153626e22f20e}\index{configurations.h@{configurations.h}!TASK\_STOP\_MOTION\_PRIORITY@{TASK\_STOP\_MOTION\_PRIORITY}}
\index{TASK\_STOP\_MOTION\_PRIORITY@{TASK\_STOP\_MOTION\_PRIORITY}!configurations.h@{configurations.h}}
\doxysubsubsection{\texorpdfstring{TASK\_STOP\_MOTION\_PRIORITY}{TASK\_STOP\_MOTION\_PRIORITY}}
{\footnotesize\ttfamily \label{configurations_8h_a6a03ad7d94899986123153626e22f20e} 
\+\#define TASK\+\_\+\+STOP\+\_\+\+MOTION\+\_\+\+PRIORITY~17}

\Hypertarget{configurations_8h_ae38a7f5e2f24d06689d8b847a35e5ccf}\index{configurations.h@{configurations.h}!TASK\_TELEMETRY\_DELAY@{TASK\_TELEMETRY\_DELAY}}
\index{TASK\_TELEMETRY\_DELAY@{TASK\_TELEMETRY\_DELAY}!configurations.h@{configurations.h}}
\doxysubsubsection{\texorpdfstring{TASK\_TELEMETRY\_DELAY}{TASK\_TELEMETRY\_DELAY}}
{\footnotesize\ttfamily \label{configurations_8h_ae38a7f5e2f24d06689d8b847a35e5ccf} 
\+\#define TASK\+\_\+\+TELEMETRY\+\_\+\+DELAY~1000}

Delay for Telemetry task (ms). \Hypertarget{configurations_8h_a8d137660d77a1310d990d0616a8c2b48}\index{configurations.h@{configurations.h}!TASK\_TELEMETRY\_PRIORITY@{TASK\_TELEMETRY\_PRIORITY}}
\index{TASK\_TELEMETRY\_PRIORITY@{TASK\_TELEMETRY\_PRIORITY}!configurations.h@{configurations.h}}
\doxysubsubsection{\texorpdfstring{TASK\_TELEMETRY\_PRIORITY}{TASK\_TELEMETRY\_PRIORITY}}
{\footnotesize\ttfamily \label{configurations_8h_a8d137660d77a1310d990d0616a8c2b48} 
\+\#define TASK\+\_\+\+TELEMETRY\+\_\+\+PRIORITY~11}

\Hypertarget{configurations_8h_af85d4f2634be8dc9a6bd6255f1f8688e}\index{configurations.h@{configurations.h}!TASK\_TRACKING\_CALCULATION\_PRIORITY@{TASK\_TRACKING\_CALCULATION\_PRIORITY}}
\index{TASK\_TRACKING\_CALCULATION\_PRIORITY@{TASK\_TRACKING\_CALCULATION\_PRIORITY}!configurations.h@{configurations.h}}
\doxysubsubsection{\texorpdfstring{TASK\_TRACKING\_CALCULATION\_PRIORITY}{TASK\_TRACKING\_CALCULATION\_PRIORITY}}
{\footnotesize\ttfamily \label{configurations_8h_af85d4f2634be8dc9a6bd6255f1f8688e} 
\+\#define TASK\+\_\+\+TRACKING\+\_\+\+CALCULATION\+\_\+\+PRIORITY~14}

\Hypertarget{configurations_8h_ab51c362d04fd48de5e648831613ceb9b}\index{configurations.h@{configurations.h}!TIMER\_PREESCALER@{TIMER\_PREESCALER}}
\index{TIMER\_PREESCALER@{TIMER\_PREESCALER}!configurations.h@{configurations.h}}
\doxysubsubsection{\texorpdfstring{TIMER\_PREESCALER}{TIMER\_PREESCALER}}
{\footnotesize\ttfamily \label{configurations_8h_ab51c362d04fd48de5e648831613ceb9b} 
\+\#define TIMER\+\_\+\+PREESCALER~80}

Prescaler → 1 MHz timer base (80 MHz /\+ 80).

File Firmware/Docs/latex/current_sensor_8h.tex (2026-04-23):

\doxysection{include/\+current\+Sensor.h File Reference}
\hypertarget{current_sensor_8h}{}\label{current_sensor_8h}\index{include/currentSensor.h@{include/currentSensor.h}}
{\ttfamily \+\#include "{}esp\+\_\+adc\+\_\+cal.\+h"{}}\newline
{\ttfamily \+\#include "{}driver/\+adc.\+h"{}}\newline
{\ttfamily \+\#include "{}driver/\+gpio.\+h"{}}\newline
{\ttfamily \+\#include "{}esp\+\_\+err.\+h"{}}\newline
{\ttfamily \+\#include "{}configurations.\+h"{}}\newline
\doxysubsubsection*{Classes}
\begin{DoxyCompactItemize}
\item 
class \doxymbox{\hyperlink{class_current_sensor}{Current\+Sensor}}
\begin{DoxyCompactList}\small\item\em Class for current reading using an ESP32 ADC channel. \end{DoxyCompactList}\end{DoxyCompactItemize}
\doxysubsubsection*{Macros}
\begin{Indent}\textbf{ ADC Configuration}\par
{\em 
\begin{DoxyItemize}
\item Constants for configuring the ESP32\textquotesingle{}s ADC unit. 
\end{DoxyItemize}}\begin{DoxyCompactItemize}
\item 
\+\#define \doxymbox{\hyperlink{current_sensor_8h_a9851d7403086e8d8ce491625b0f8863d}{ADC\+\_\+\+ATTEN}}~ADC\+\_\+\+ATTEN\+\_\+\+DB\+\_\+0
\begin{DoxyCompactList}\small\item\em ADC attenuation (range of 100 mV to 950 mV) for high precision. \end{DoxyCompactList}\item 
\+\#define \doxymbox{\hyperlink{current_sensor_8h_a7274e11e5026e6364ff703661611b25e}{ADC\+\_\+\+NUM\+\_\+1}}~ADC\+\_\+\+UNIT\+\_\+1
\begin{DoxyCompactList}\small\item\em ADC unit used (ADC1). \end{DoxyCompactList}\item 
\+\#define \doxymbox{\hyperlink{current_sensor_8h_ae7be6136584e673152582baf499d6a6c}{ADC\+\_\+\+WIDTH}}~ADC\+\_\+\+WIDTH\+\_\+\+BIT\+\_\+12
\begin{DoxyCompactList}\small\item\em ADC resolution (12 bits = 4096 levels). \end{DoxyCompactList}\item 
\+\#define \doxymbox{\hyperlink{current_sensor_8h_a60a309e5f8aedc2bd1244ff2ccbd6aef}{ADC\+\_\+\+DEFAULT\+\_\+\+VREF}}~1100
\begin{DoxyCompactList}\small\item\em Default value of the internal ADC reference voltage (in mV). \end{DoxyCompactList}\end{DoxyCompactItemize}
\end{Indent}
\begin{Indent}\textbf{ Current Measurement Constants}\par
{\em 
\begin{DoxyItemize}
\item Constants specific to the current measurement circuit. 
\end{DoxyItemize}}\begin{DoxyCompactItemize}
\item 
\+\#define \doxymbox{\hyperlink{current_sensor_8h_a346a50287e4a12724a4a2a39fd2f0896}{DEFAULT\+\_\+\+SHUNT\+\_\+\+VALUE\+\_\+\+OHM}}~0.\+22f
\begin{DoxyCompactList}\small\item\em Shunt resistor value in Ohms. \end{DoxyCompactList}\item 
\+\#define \doxymbox{\hyperlink{current_sensor_8h_a52d0c7ade9b2a1f9ef105779021763b8}{DEFAULT\+\_\+\+OPAMP\+\_\+\+GAIN}}~2.\+12f
\begin{DoxyCompactList}\small\item\em Operational amplifier gain. \end{DoxyCompactList}\end{DoxyCompactItemize}
\end{Indent}

\label{doc-define-members}
\Hypertarget{current_sensor_8h_doc-define-members}
\doxysubsection{Macro Definition Documentation}
\Hypertarget{current_sensor_8h_a9851d7403086e8d8ce491625b0f8863d}\index{currentSensor.h@{currentSensor.h}!ADC\_ATTEN@{ADC\_ATTEN}}
\index{ADC\_ATTEN@{ADC\_ATTEN}!currentSensor.h@{currentSensor.h}}
\doxysubsubsection{\texorpdfstring{ADC\_ATTEN}{ADC\_ATTEN}}
{\footnotesize\ttfamily \label{current_sensor_8h_a9851d7403086e8d8ce491625b0f8863d} 
\+\#define ADC\+\_\+\+ATTEN~ADC\+\_\+\+ATTEN\+\_\+\+DB\+\_\+0}

ADC attenuation (range of 100 mV to 950 mV) for high precision. 

\Hypertarget{current_sensor_8h_a60a309e5f8aedc2bd1244ff2ccbd6aef}\index{currentSensor.h@{currentSensor.h}!ADC\_DEFAULT\_VREF@{ADC\_DEFAULT\_VREF}}
\index{ADC\_DEFAULT\_VREF@{ADC\_DEFAULT\_VREF}!currentSensor.h@{currentSensor.h}}
\doxysubsubsection{\texorpdfstring{ADC\_DEFAULT\_VREF}{ADC\_DEFAULT\_VREF}}
{\footnotesize\ttfamily \label{current_sensor_8h_a60a309e5f8aedc2bd1244ff2ccbd6aef} 
\+\#define ADC\+\_\+\+DEFAULT\+\_\+\+VREF~1100}

Default value of the internal ADC reference voltage (in mV). 

\Hypertarget{current_sensor_8h_a7274e11e5026e6364ff703661611b25e}\index{currentSensor.h@{currentSensor.h}!ADC\_NUM\_1@{ADC\_NUM\_1}}
\index{ADC\_NUM\_1@{ADC\_NUM\_1}!currentSensor.h@{currentSensor.h}}
\doxysubsubsection{\texorpdfstring{ADC\_NUM\_1}{ADC\_NUM\_1}}
{\footnotesize\ttfamily \label{current_sensor_8h_a7274e11e5026e6364ff703661611b25e} 
\+\#define ADC\+\_\+\+NUM\+\_\+1~ADC\+\_\+\+UNIT\+\_\+1}

ADC unit used (ADC1). 

\Hypertarget{current_sensor_8h_ae7be6136584e673152582baf499d6a6c}\index{currentSensor.h@{currentSensor.h}!ADC\_WIDTH@{ADC\_WIDTH}}
\index{ADC\_WIDTH@{ADC\_WIDTH}!currentSensor.h@{currentSensor.h}}
\doxysubsubsection{\texorpdfstring{ADC\_WIDTH}{ADC\_WIDTH}}
{\footnotesize\ttfamily \label{current_sensor_8h_ae7be6136584e673152582baf499d6a6c} 
\+\#define ADC\+\_\+\+WIDTH~ADC\+\_\+\+WIDTH\+\_\+\+BIT\+\_\+12}

ADC resolution (12 bits = 4096 levels). 

\Hypertarget{current_sensor_8h_a52d0c7ade9b2a1f9ef105779021763b8}\index{currentSensor.h@{currentSensor.h}!DEFAULT\_OPAMP\_GAIN@{DEFAULT\_OPAMP\_GAIN}}
\index{DEFAULT\_OPAMP\_GAIN@{DEFAULT\_OPAMP\_GAIN}!currentSensor.h@{currentSensor.h}}
\doxysubsubsection{\texorpdfstring{DEFAULT\_OPAMP\_GAIN}{DEFAULT\_OPAMP\_GAIN}}
{\footnotesize\ttfamily \label{current_sensor_8h_a52d0c7ade9b2a1f9ef105779021763b8} 
\+\#define DEFAULT\+\_\+\+OPAMP\+\_\+\+GAIN~2.\+12f}

Operational amplifier gain. 

\Hypertarget{current_sensor_8h_a346a50287e4a12724a4a2a39fd2f0896}\index{currentSensor.h@{currentSensor.h}!DEFAULT\_SHUNT\_VALUE\_OHM@{DEFAULT\_SHUNT\_VALUE\_OHM}}
\index{DEFAULT\_SHUNT\_VALUE\_OHM@{DEFAULT\_SHUNT\_VALUE\_OHM}!currentSensor.h@{currentSensor.h}}
\doxysubsubsection{\texorpdfstring{DEFAULT\_SHUNT\_VALUE\_OHM}{DEFAULT\_SHUNT\_VALUE\_OHM}}
{\footnotesize\ttfamily \label{current_sensor_8h_a346a50287e4a12724a4a2a39fd2f0896} 
\+\#define DEFAULT\+\_\+\+SHUNT\+\_\+\+VALUE\+\_\+\+OHM~0.\+22f}

Shunt resistor value in Ohms.

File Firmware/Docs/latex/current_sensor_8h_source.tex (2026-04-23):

\doxysection{current\+Sensor.\+h}
\hypertarget{current_sensor_8h_source}{}\label{current_sensor_8h_source}\index{include/currentSensor.h@{include/currentSensor.h}}
\doxymbox{\hyperlink{current_sensor_8h}{Go to the documentation of this file.}}
\begin{DoxyCode}{0}
\DoxyCodeLine{00001\ }
\DoxyCodeLine{00011\ }
\DoxyCodeLine{00012\ \textcolor{preprocessor}{\#ifndef\ CURRENT\_H}}
\DoxyCodeLine{00013\ \textcolor{preprocessor}{\#define\ CURRENT\_H}}
\DoxyCodeLine{00014\ }
\DoxyCodeLine{00015\ \textcolor{preprocessor}{\#include\ "{}esp\_adc\_cal.h"{}}}
\DoxyCodeLine{00016\ \textcolor{preprocessor}{\#include\ "{}driver/adc.h"{}}}
\DoxyCodeLine{00017\ \textcolor{preprocessor}{\#include\ "{}driver/gpio.h"{}}}
\DoxyCodeLine{00018\ \textcolor{preprocessor}{\#include\ "{}esp\_err.h"{}}}
\DoxyCodeLine{00019\ \textcolor{preprocessor}{\#include\ "{}\doxymbox{\hyperlink{configurations_8h}{configurations.h}}"{}}}
\DoxyCodeLine{00020\ }
\DoxyCodeLine{00026\ \textcolor{preprocessor}{\#define\ ADC\_ATTEN\ \ \ \ \ \ \ \ \ \ \ ADC\_ATTEN\_DB\_0}\textcolor{preprocessor}{}}
\DoxyCodeLine{00028\ \textcolor{preprocessor}{\#define\ ADC\_NUM\_1\ \ \ \ \ \ \ \ \ \ \ ADC\_UNIT\_1}\textcolor{preprocessor}{}}
\DoxyCodeLine{00030\ \textcolor{preprocessor}{\#define\ ADC\_WIDTH\ \ \ \ \ \ \ \ \ \ \ ADC\_WIDTH\_BIT\_12}\textcolor{preprocessor}{}}
\DoxyCodeLine{00032\ \textcolor{preprocessor}{\#define\ ADC\_DEFAULT\_VREF\ \ \ \ 1100}\textcolor{preprocessor}{}}
\DoxyCodeLine{00034\ }
\DoxyCodeLine{00040\ \textcolor{preprocessor}{\#define\ DEFAULT\_SHUNT\_VALUE\_OHM\ 0.22f}\textcolor{preprocessor}{}}
\DoxyCodeLine{00042\ \textcolor{preprocessor}{\#define\ DEFAULT\_OPAMP\_GAIN\ \ \ \ \ \ 2.12f}\textcolor{preprocessor}{}}
\DoxyCodeLine{00044\ }
\DoxyCodeLine{00053\ \textcolor{keyword}{class\ }\doxymbox{\hyperlink{class_current_sensor_ac5f9b3a18305619e5c668141896a5bd8}{CurrentSensor}}}
\DoxyCodeLine{00054\ \{}
\DoxyCodeLine{00055\ \textcolor{keyword}{private}:}
\DoxyCodeLine{00056\ \ \ \ \ adc1\_channel\_t\ \doxymbox{\hyperlink{class_current_sensor_a7d8f28a1e11b027c2a30812dbf2daceb}{channel}};\ \ \ \ \ \ \ \ \ \ \ \ \ \ \ \ \ \ }
\DoxyCodeLine{00057\ \ \ \ \ esp\_adc\_cal\_characteristics\_t\ \doxymbox{\hyperlink{class_current_sensor_acad693f0e83b428794877a86cace4e8b}{adc\_chars}};\ }
\DoxyCodeLine{00058\ \ \ \ \ uint32\_t\ \doxymbox{\hyperlink{class_current_sensor_a9df470ef7d32b668732aad55bce142a2}{offset\_mV}}\ =\ 0;\ \ \ \ \ \ \ \ \ \ \ \ \ \ \ \ \ \ }
\DoxyCodeLine{00059\ \ \ \ \ \textcolor{keywordtype}{float}\ \doxymbox{\hyperlink{class_current_sensor_a696410e1f762478481cd91931841dc08}{shunt\_ohm}}\ =\ \doxymbox{\hyperlink{current_sensor_8h_a346a50287e4a12724a4a2a39fd2f0896}{DEFAULT\_SHUNT\_VALUE\_OHM}};\ }
\DoxyCodeLine{00060\ \ \ \ \ \textcolor{keywordtype}{float}\ \doxymbox{\hyperlink{class_current_sensor_acc6cb6dce83074c330c43ef33d8a28ff}{opamp\_gain}}\ =\ \doxymbox{\hyperlink{current_sensor_8h_a52d0c7ade9b2a1f9ef105779021763b8}{DEFAULT\_OPAMP\_GAIN}};\ \ \ }
\DoxyCodeLine{00061\ }
\DoxyCodeLine{00068\ \ \ \ \ uint32\_t\ \doxymbox{\hyperlink{class_current_sensor_a25264c716d01a1a6051e6d10cc628768}{multisample}}(uint8\_t\ samples);}
\DoxyCodeLine{00069\ }
\DoxyCodeLine{00070\ \textcolor{keyword}{public}:}
\DoxyCodeLine{00079\ \ \ \ \ \doxymbox{\hyperlink{class_current_sensor_ac5f9b3a18305619e5c668141896a5bd8}{CurrentSensor}}(adc1\_channel\_t\ \doxymbox{\hyperlink{class_current_sensor_a7d8f28a1e11b027c2a30812dbf2daceb}{channel}});}
\DoxyCodeLine{00080\ }
\DoxyCodeLine{00090\ \ \ \ \ \textcolor{keywordtype}{float}\ \doxymbox{\hyperlink{class_current_sensor_aeb622e3e92cc15b0bc03af867df0d6c8}{getCurrent\_mA}}();}
\DoxyCodeLine{00091\ }
\DoxyCodeLine{00100\ \ \ \ \ uint32\_t\ \doxymbox{\hyperlink{class_current_sensor_ab6064868042388af7b1b384943487d06}{getShuntVoltage\_mV}}();}
\DoxyCodeLine{00101\ }
\DoxyCodeLine{00109\ \ \ \ \ \textcolor{keywordtype}{void}\ \doxymbox{\hyperlink{class_current_sensor_ac58c640607e8be98331b20bae3464f07}{calibrateOffset}}();}
\DoxyCodeLine{00110\ }
\DoxyCodeLine{00115\ \ \ \ \ uint32\_t\ \doxymbox{\hyperlink{class_current_sensor_a1c11f880b95ae27ecf7dc2a8357f7178}{getOffset\_mV}}();}
\DoxyCodeLine{00116\ }
\DoxyCodeLine{00121\ \ \ \ \ \textcolor{keywordtype}{void}\ \doxymbox{\hyperlink{class_current_sensor_a2a3d752e19552d7f8be02ee02e75ecb1}{setShuntValue}}(\textcolor{keywordtype}{float}\ \doxymbox{\hyperlink{class_current_sensor_a696410e1f762478481cd91931841dc08}{shunt\_ohm}});}
\DoxyCodeLine{00122\ \ \ \ \ }
\DoxyCodeLine{00127\ \ \ \ \ \textcolor{keywordtype}{void}\ \doxymbox{\hyperlink{class_current_sensor_aea8c65c5f8f5e04583b446393a0aaa89}{setOpAmpGain}}(\textcolor{keywordtype}{float}\ gain);}
\DoxyCodeLine{00128\ \};}
\DoxyCodeLine{00129\ }
\DoxyCodeLine{00130\ \textcolor{preprocessor}{\#endif\ }\textcolor{comment}{//\ CURRENT\_H}}

\end{DoxyCode}

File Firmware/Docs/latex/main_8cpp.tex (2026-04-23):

\doxysection{src/\+main.cpp File Reference}
\hypertarget{main_8cpp}{}\label{main_8cpp}\index{src/main.cpp@{src/main.cpp}}
{\ttfamily \+\#include "{}utils.\+h"{}}\newline
{\ttfamily \+\#include "{}PI\+\_\+\+Controller.\+h"{}}\newline
{\ttfamily \+\#include "{}server.\+h"{}}\newline
{\ttfamily \+\#include "{}current\+Sensor.\+h"{}}\newline
{\ttfamily \+\#include "{}reed.\+h"{}}\newline
{\ttfamily \+\#include "{}motor\+Driver.\+h"{}}\newline
{\ttfamily \+\#include "{}configurations.\+h"{}}\newline
\doxysubsubsection*{Functions}
\begin{DoxyCompactItemize}
\item 
Hardware\+Serial \doxymbox{\hyperlink{main_8cpp_aa9d2f9a14d5cc2f236faff4c3b095783}{gps\+Serial}} (\doxymbox{\hyperlink{configurations_8h_a0276fa67794ae64b565fe0da6db4fc9d}{GPS\+\_\+\+UART}})
\item 
void IRAM\+\_\+\+ATTR \doxymbox{\hyperlink{main_8cpp_a1dd4b93df00922d511a5f6925175bc6a}{reed\+Az\+\_\+event\+\_\+handler}} (void \texorpdfstring{$\ast$}{*}arg)
\item 
void IRAM\+\_\+\+ATTR \doxymbox{\hyperlink{main_8cpp_ab8fa2c4464e56c5bc776469aadd26360}{reed\+El\+\_\+event\+\_\+handler}} (void \texorpdfstring{$\ast$}{*}arg)
\item 
void \doxymbox{\hyperlink{main_8cpp_a5402996288dcbab1df2ffbafda7d0985}{control\+Timer\+\_\+\+ISR}} (void \texorpdfstring{$\ast$}{*}arg)
\item 
void \doxymbox{\hyperlink{main_8cpp_a6d1916a61bfaa459847afb810ae15e86}{GPS\+\_\+\+Task}} (void \texorpdfstring{$\ast$}{*}pv\+Parameters)
\item 
void \doxymbox{\hyperlink{main_8cpp_abde6d73b52e488a03bf8a31fddbeb554}{Tracking\+Predictor\+\_\+\+Task}} (void \texorpdfstring{$\ast$}{*}pv\+Parameters)
\item 
void \doxymbox{\hyperlink{main_8cpp_adf5de4c65ad946ce5eb1139a9ee94d1b}{Motion\+Control\+\_\+\+Task}} (void \texorpdfstring{$\ast$}{*}pv\+Parameters)
\item 
void \doxymbox{\hyperlink{main_8cpp_aab021fe7caed981cc28cbcd3ceb9a00f}{Stop\+Motion\+\_\+\+Task}} (void \texorpdfstring{$\ast$}{*}pv\+Parameters)
\item 
void \doxymbox{\hyperlink{main_8cpp_ae6d71ec394438a8016b4e129fdad483d}{Calibration\+\_\+\+Task}} (void \texorpdfstring{$\ast$}{*}pv\+Parameters)
\item 
void \doxymbox{\hyperlink{main_8cpp_a2ea8a96e91a3c3fc270e8608157fdcc1}{Current\+Monitor\+\_\+\+Task}} (void \texorpdfstring{$\ast$}{*}pv\+Parameters)
\item 
void \doxymbox{\hyperlink{main_8cpp_a5ca458d67906822bc0070de63d3bab8f}{telemetry\+\_\+\+Task}} (void \texorpdfstring{$\ast$}{*}pv\+Parameters)
\item 
void \doxymbox{\hyperlink{main_8cpp_a4fc01d736fe50cf5b977f755b675f11d}{setup}} ()
\item 
void \doxymbox{\hyperlink{main_8cpp_afe461d27b9c48d5921c00d521181f12f}{loop}} ()
\end{DoxyCompactItemize}
\doxysubsubsection*{Variables}
\begin{DoxyCompactItemize}
\item 
Sgp4 \doxymbox{\hyperlink{main_8cpp_a7a8e6488a647b64ac7902070f7d3a373}{satellite}}
\begin{DoxyCompactList}\small\item\em Global SGP4 object for satellite orbit prediction. \end{DoxyCompactList}\item 
Preferences \doxymbox{\hyperlink{main_8cpp_a95d592edb81dd40b1f9085628e7698a8}{config}}
\begin{DoxyCompactList}\small\item\em Global object for managing persistent configuration data (NVS). \end{DoxyCompactList}\item 
Tiny\+GPSPlus \doxymbox{\hyperlink{main_8cpp_a169c53997a7da1d0fb99aec1b4675ce8}{gps}}
\item 
\doxymbox{\hyperlink{class_server_handler}{Server\+Handler}} \doxymbox{\hyperlink{main_8cpp_a30f0d942420b66dee65de9c062b2466b}{server\+Handler}} (\doxymbox{\hyperlink{configurations_8h_af257e2a3e091629829857a2eb8931a7a}{DEFAULT\+\_\+\+SERVER\+\_\+\+PORT}})
\item 
\doxymbox{\hyperlink{class_p_i___controller}{PI\+\_\+\+Controller}} \doxymbox{\hyperlink{main_8cpp_ac4a9a510f261e05b2f128b05c332b242}{controller\+Az}} (\doxymbox{\hyperlink{configurations_8h_aeb86acb27e54b9755fcdac7881be9a67}{KP\+\_\+\+AZIMUTH}}, \doxymbox{\hyperlink{configurations_8h_a84c8a48add65471b6d7a3df86ded588a}{KI\+\_\+\+AZIMUTH}}, \doxymbox{\hyperlink{configurations_8h_a048e4fab329b80f602ac97b6aed12979}{SAMPLE\+\_\+\+TIME\+\_\+S}}, \doxymbox{\hyperlink{configurations_8h_af612d680313c8e405272d106245d0fe6}{M\+\_\+\+AZ\+\_\+\+V\+\_\+\+TO\+\_\+\+START}}, \doxymbox{\hyperlink{configurations_8h_a114551a5238cb0c6d988e55ba1d563c1}{M\+\_\+\+V\+\_\+\+NOMINAL}})
\item 
\doxymbox{\hyperlink{class_p_i___controller}{PI\+\_\+\+Controller}} \doxymbox{\hyperlink{main_8cpp_a5373cc9382078d0e12734ddfe3d352c2}{controller\+El}} (\doxymbox{\hyperlink{configurations_8h_aa837cea21a670725c8482e7379c50b84}{KP\+\_\+\+ELEVATION}}, \doxymbox{\hyperlink{configurations_8h_a9f3f39cf87464e2b698790a8d22894d4}{KI\+\_\+\+ELEVATION}}, \doxymbox{\hyperlink{configurations_8h_a048e4fab329b80f602ac97b6aed12979}{SAMPLE\+\_\+\+TIME\+\_\+S}}, \doxymbox{\hyperlink{configurations_8h_afd517c26a46c866b3e18cf00c0e9b24b}{M\+\_\+\+EL\+\_\+\+V\+\_\+\+TO\+\_\+\+START}}, \doxymbox{\hyperlink{configurations_8h_a114551a5238cb0c6d988e55ba1d563c1}{M\+\_\+\+V\+\_\+\+NOMINAL}})
\item 
\doxymbox{\hyperlink{class_reed_switch}{Reed\+Switch}} \doxymbox{\hyperlink{main_8cpp_a2c5a73a4c30d5441190eb5440c7d971b}{reed\+Az}} (\doxymbox{\hyperlink{configurations_8h_aa87d687897e717dea73184063e2b3be1}{REED\+\_\+\+AZ\+\_\+\+PIN}}, PCNT\+\_\+\+UNIT\+\_\+0, PCNT\+\_\+\+CHANNEL\+\_\+0, \doxymbox{\hyperlink{configurations_8h_acdaca90d9569b370599f231928e32845}{REED\+\_\+\+AZ\+\_\+\+SOFT\+\_\+\+LIMIT\+\_\+\+LOW}}, \doxymbox{\hyperlink{configurations_8h_a9fc5bef92112470db8255986b6ecebcb}{REED\+\_\+\+AZ\+\_\+\+SOFT\+\_\+\+LIMIT\+\_\+\+HIGH}}, \doxymbox{\hyperlink{main_8cpp_a1dd4b93df00922d511a5f6925175bc6a}{reed\+Az\+\_\+event\+\_\+handler}})
\item 
\doxymbox{\hyperlink{class_reed_switch}{Reed\+Switch}} \doxymbox{\hyperlink{main_8cpp_a32c123ba4604b420b78493bc54f3ede4}{reed\+El}} (\doxymbox{\hyperlink{configurations_8h_ac623bf5b9b1b5e841f3d5358f5ce36f7}{REED\+\_\+\+EL\+\_\+\+PIN}}, PCNT\+\_\+\+UNIT\+\_\+1, PCNT\+\_\+\+CHANNEL\+\_\+0, \doxymbox{\hyperlink{configurations_8h_a08a68068b1a658d3b0e967b799a84100}{REED\+\_\+\+EL\+\_\+\+SOFT\+\_\+\+LIMIT\+\_\+\+LOW}}, \doxymbox{\hyperlink{configurations_8h_a7de64bbb117e66e561add80d7f24374e}{REED\+\_\+\+EL\+\_\+\+SOFT\+\_\+\+LIMIT\+\_\+\+HIGH}}, \doxymbox{\hyperlink{main_8cpp_ab8fa2c4464e56c5bc776469aadd26360}{reed\+El\+\_\+event\+\_\+handler}})
\item 
\doxymbox{\hyperlink{class_motor_driver}{Motor\+Driver}} \doxymbox{\hyperlink{main_8cpp_a71c3efb3b6c68db64b67301de23c2c47}{motor\+Az}} (\doxymbox{\hyperlink{configurations_8h_a9ce983ce5b08d7846d8fa31118021b24}{IN1\+\_\+\+AZ\+\_\+\+PIN}}, \doxymbox{\hyperlink{configurations_8h_a9d57a6e7ffc17486374ef9dc813b76f4}{IN2\+\_\+\+AZ\+\_\+\+PIN}}, \doxymbox{\hyperlink{configurations_8h_ab18abfaf88f25a5ba352779defd5b333}{EN\+\_\+\+AZ\+\_\+\+PIN}}, LEDC\+\_\+\+TIMER\+\_\+0, LEDC\+\_\+\+CHANNEL\+\_\+0, \doxymbox{\hyperlink{configurations_8h_a56e165627f596c2f42f843ae6571de0e}{PWM\+\_\+\+FREQ\+\_\+\+HZ}})
\item 
\doxymbox{\hyperlink{class_motor_driver}{Motor\+Driver}} \doxymbox{\hyperlink{main_8cpp_a75ce768f93f1fd4332896623d2635209}{motor\+El}} (\doxymbox{\hyperlink{configurations_8h_a2f5dd98516c40e68c6da603ddcab8698}{IN1\+\_\+\+EL\+\_\+\+PIN}}, \doxymbox{\hyperlink{configurations_8h_a3c8358b42b349a816f9ef990377fd98b}{IN2\+\_\+\+EL\+\_\+\+PIN}}, \doxymbox{\hyperlink{configurations_8h_a48348f346a55b4cdd6249e8d8491242d}{EN\+\_\+\+EL\+\_\+\+PIN}}, LEDC\+\_\+\+TIMER\+\_\+0, LEDC\+\_\+\+CHANNEL\+\_\+1, \doxymbox{\hyperlink{configurations_8h_a56e165627f596c2f42f843ae6571de0e}{PWM\+\_\+\+FREQ\+\_\+\+HZ}})
\item 
\doxymbox{\hyperlink{class_current_sensor}{Current\+Sensor}} \doxymbox{\hyperlink{main_8cpp_a4bc81131529c2d9516c48205ad81ab20}{current\+Az}} (\doxymbox{\hyperlink{configurations_8h_a4c9747a154da64ff447148d8d4fa5a20}{I\+\_\+\+AZ\+\_\+\+CHANNEL}})
\item 
\doxymbox{\hyperlink{class_current_sensor}{Current\+Sensor}} \doxymbox{\hyperlink{main_8cpp_a5bde5389f1e43c031d8188a5f6d5ae98}{current\+El}} (\doxymbox{\hyperlink{configurations_8h_a879a26029e799249e6786c5890d9f7e1}{I\+\_\+\+EL\+\_\+\+CHANNEL}})
\item 
Task\+Handle\+\_\+t \doxymbox{\hyperlink{main_8cpp_a31044d4fc6e109ea0df731c5e5c559ea}{GPS\+\_\+\+Task\+Handle}} = NULL
\item 
Task\+Handle\+\_\+t \doxymbox{\hyperlink{main_8cpp_abefc65e0e269b258dd4ed3f4c340658a}{Tracking\+Predictor\+\_\+\+Task\+Handle}} = NULL
\item 
Task\+Handle\+\_\+t \doxymbox{\hyperlink{main_8cpp_aee44830b05e02ea9dd8829f08f3fbb8e}{Motion\+Control\+\_\+\+Task\+Handle}} = NULL
\item 
Task\+Handle\+\_\+t \doxymbox{\hyperlink{main_8cpp_a76bda418f1aad970979562c0a0d5ecd4}{Stop\+Motion\+\_\+\+Task\+Handle}} = NULL
\item 
Task\+Handle\+\_\+t \doxymbox{\hyperlink{main_8cpp_a5f8db47b664833fcd348f6d72d7ff77e}{Calibration\+\_\+\+Task\+Handle}} = NULL
\item 
static const char \texorpdfstring{$\ast$}{*} \doxymbox{\hyperlink{main_8cpp_a5a85b9c772bbeb480b209a3e6ea92b4c}{TAG}} = "{}MAIN"{}
\item 
\doxymbox{\hyperlink{utils_8h_aa27ea2fa6386a731820fdc8ed72ab361}{spherical\+Angles\+\_\+t}} \doxymbox{\hyperlink{main_8cpp_a00ee04c34be775944fa477ad9d975031}{target\+Angle}} = \{0\}
\item 
\doxymbox{\hyperlink{utils_8h_aa27ea2fa6386a731820fdc8ed72ab361}{spherical\+Angles\+\_\+t}} \doxymbox{\hyperlink{main_8cpp_abb195f07774e5b37386632d27be9fcfd}{sgp4\+Target\+Angle}} = \{0\}
\begin{DoxyCompactList}\small\item\em Global structure for the target (commanded) antenna position. \end{DoxyCompactList}\item 
\doxymbox{\hyperlink{utils_8h_aa27ea2fa6386a731820fdc8ed72ab361}{spherical\+Angles\+\_\+t}} \doxymbox{\hyperlink{main_8cpp_a128fc44694041af0e517137708eb73fb}{manual\+Target\+Angle}} = \{0\}
\item 
\doxymbox{\hyperlink{utils_8h_aa27ea2fa6386a731820fdc8ed72ab361}{spherical\+Angles\+\_\+t}} \doxymbox{\hyperlink{main_8cpp_a47f50d5a92efa4cb35b7c0e5e247cb27}{set\+Point\+Angle}} = \{0\}
\item 
\doxymbox{\hyperlink{utils_8h_aa27ea2fa6386a731820fdc8ed72ab361}{spherical\+Angles\+\_\+t}} \doxymbox{\hyperlink{main_8cpp_a7612bbada92b5c10ddfcd3e5251e258b}{mount\+Angle}} = \{0\}
\begin{DoxyCompactList}\small\item\em Global structure for the current (measured) antenna position. \end{DoxyCompactList}\item 
\doxymbox{\hyperlink{utils_8h_aa27ea2fa6386a731820fdc8ed72ab361}{spherical\+Angles\+\_\+t}} \doxymbox{\hyperlink{main_8cpp_a64f04e683eecc9224b4e930d088f89fb}{offset\+Angle}} = \{0\}
\item 
\doxymbox{\hyperlink{utils_8h_a4e531e11ab017aad416f0432e33e1a31}{mount\+Flags\+\_\+t}} \doxymbox{\hyperlink{main_8cpp_a13242e46cf88322a36d0a21f463814d6}{flags}}
\begin{DoxyCompactList}\small\item\em Global structure holding the current mount flags. \end{DoxyCompactList}\item 
\doxymbox{\hyperlink{utils_8h_af8a35661022926a438bb0e33cf4e84d2}{tracker\+Status\+\_\+t}} \doxymbox{\hyperlink{main_8cpp_ae231754aa856e7e4956e423e1b308ee9}{status}}
\begin{DoxyCompactList}\small\item\em Global structure holding the current operational status of the tracker. \end{DoxyCompactList}\item 
unsigned long \doxymbox{\hyperlink{main_8cpp_a46e1484ba8c7792f044d44dc3e9594c4}{next\+Pass\+\_\+unix}} = 0
\begin{DoxyCompactList}\small\item\em Next pass start time in unix. \end{DoxyCompactList}\end{DoxyCompactItemize}

\label{doc-func-members}
\Hypertarget{main_8cpp_doc-func-members}
\doxysubsection{Function Documentation}
\Hypertarget{main_8cpp_ae6d71ec394438a8016b4e129fdad483d}\index{main.cpp@{main.cpp}!Calibration\_Task@{Calibration\_Task}}
\index{Calibration\_Task@{Calibration\_Task}!main.cpp@{main.cpp}}
\doxysubsubsection{\texorpdfstring{Calibration\_Task()}{Calibration\_Task()}}
{\footnotesize\ttfamily \label{main_8cpp_ae6d71ec394438a8016b4e129fdad483d} 
void Calibration\+\_\+\+Task (\begin{DoxyParamCaption}\item[{void \texorpdfstring{$\ast$}{*}}]{pv\+Parameters}{}\end{DoxyParamCaption})}

\Hypertarget{main_8cpp_a5402996288dcbab1df2ffbafda7d0985}\index{main.cpp@{main.cpp}!controlTimer\_ISR@{controlTimer\_ISR}}
\index{controlTimer\_ISR@{controlTimer\_ISR}!main.cpp@{main.cpp}}
\doxysubsubsection{\texorpdfstring{controlTimer\_ISR()}{controlTimer\_ISR()}}
{\footnotesize\ttfamily \label{main_8cpp_a5402996288dcbab1df2ffbafda7d0985} 
void IRAM\+\_\+\+ATTR control\+Timer\+\_\+\+ISR (\begin{DoxyParamCaption}\item[{void \texorpdfstring{$\ast$}{*}}]{arg}{}\end{DoxyParamCaption})}

\Hypertarget{main_8cpp_a2ea8a96e91a3c3fc270e8608157fdcc1}\index{main.cpp@{main.cpp}!CurrentMonitor\_Task@{CurrentMonitor\_Task}}
\index{CurrentMonitor\_Task@{CurrentMonitor\_Task}!main.cpp@{main.cpp}}
\doxysubsubsection{\texorpdfstring{CurrentMonitor\_Task()}{CurrentMonitor\_Task()}}
{\footnotesize\ttfamily \label{main_8cpp_a2ea8a96e91a3c3fc270e8608157fdcc1} 
void Current\+Monitor\+\_\+\+Task (\begin{DoxyParamCaption}\item[{void \texorpdfstring{$\ast$}{*}}]{pv\+Parameters}{}\end{DoxyParamCaption})}

\Hypertarget{main_8cpp_a6d1916a61bfaa459847afb810ae15e86}\index{main.cpp@{main.cpp}!GPS\_Task@{GPS\_Task}}
\index{GPS\_Task@{GPS\_Task}!main.cpp@{main.cpp}}
\doxysubsubsection{\texorpdfstring{GPS\_Task()}{GPS\_Task()}}
{\footnotesize\ttfamily \label{main_8cpp_a6d1916a61bfaa459847afb810ae15e86} 
void GPS\+\_\+\+Task (\begin{DoxyParamCaption}\item[{void \texorpdfstring{$\ast$}{*}}]{pv\+Parameters}{}\end{DoxyParamCaption})}

\Hypertarget{main_8cpp_aa9d2f9a14d5cc2f236faff4c3b095783}\index{main.cpp@{main.cpp}!gpsSerial@{gpsSerial}}
\index{gpsSerial@{gpsSerial}!main.cpp@{main.cpp}}
\doxysubsubsection{\texorpdfstring{gpsSerial()}{gpsSerial()}}
{\footnotesize\ttfamily \label{main_8cpp_aa9d2f9a14d5cc2f236faff4c3b095783} 
Hardware\+Serial gps\+Serial (\begin{DoxyParamCaption}\item[{\doxymbox{\hyperlink{configurations_8h_a0276fa67794ae64b565fe0da6db4fc9d}{GPS\+\_\+\+UART}}}]{}{}\end{DoxyParamCaption})}

\Hypertarget{main_8cpp_afe461d27b9c48d5921c00d521181f12f}\index{main.cpp@{main.cpp}!loop@{loop}}
\index{loop@{loop}!main.cpp@{main.cpp}}
\doxysubsubsection{\texorpdfstring{loop()}{loop()}}
{\footnotesize\ttfamily \label{main_8cpp_afe461d27b9c48d5921c00d521181f12f} 
void loop (\begin{DoxyParamCaption}{}{}\end{DoxyParamCaption})}

\Hypertarget{main_8cpp_adf5de4c65ad946ce5eb1139a9ee94d1b}\index{main.cpp@{main.cpp}!MotionControl\_Task@{MotionControl\_Task}}
\index{MotionControl\_Task@{MotionControl\_Task}!main.cpp@{main.cpp}}
\doxysubsubsection{\texorpdfstring{MotionControl\_Task()}{MotionControl\_Task()}}
{\footnotesize\ttfamily \label{main_8cpp_adf5de4c65ad946ce5eb1139a9ee94d1b} 
void Motion\+Control\+\_\+\+Task (\begin{DoxyParamCaption}\item[{void \texorpdfstring{$\ast$}{*}}]{pv\+Parameters}{}\end{DoxyParamCaption})}

\Hypertarget{main_8cpp_a1dd4b93df00922d511a5f6925175bc6a}\index{main.cpp@{main.cpp}!reedAz\_event\_handler@{reedAz\_event\_handler}}
\index{reedAz\_event\_handler@{reedAz\_event\_handler}!main.cpp@{main.cpp}}
\doxysubsubsection{\texorpdfstring{reedAz\_event\_handler()}{reedAz\_event\_handler()}}
{\footnotesize\ttfamily \label{main_8cpp_a1dd4b93df00922d511a5f6925175bc6a} 
void IRAM\+\_\+\+ATTR reed\+Az\+\_\+event\+\_\+handler (\begin{DoxyParamCaption}\item[{void \texorpdfstring{$\ast$}{*}}]{arg}{}\end{DoxyParamCaption})}

\Hypertarget{main_8cpp_ab8fa2c4464e56c5bc776469aadd26360}\index{main.cpp@{main.cpp}!reedEl\_event\_handler@{reedEl\_event\_handler}}
\index{reedEl\_event\_handler@{reedEl\_event\_handler}!main.cpp@{main.cpp}}
\doxysubsubsection{\texorpdfstring{reedEl\_event\_handler()}{reedEl\_event\_handler()}}
{\footnotesize\ttfamily \label{main_8cpp_ab8fa2c4464e56c5bc776469aadd26360} 
void IRAM\+\_\+\+ATTR reed\+El\+\_\+event\+\_\+handler (\begin{DoxyParamCaption}\item[{void \texorpdfstring{$\ast$}{*}}]{arg}{}\end{DoxyParamCaption})}

\Hypertarget{main_8cpp_a4fc01d736fe50cf5b977f755b675f11d}\index{main.cpp@{main.cpp}!setup@{setup}}
\index{setup@{setup}!main.cpp@{main.cpp}}
\doxysubsubsection{\texorpdfstring{setup()}{setup()}}
{\footnotesize\ttfamily \label{main_8cpp_a4fc01d736fe50cf5b977f755b675f11d} 
void setup (\begin{DoxyParamCaption}{}{}\end{DoxyParamCaption})}

\Hypertarget{main_8cpp_aab021fe7caed981cc28cbcd3ceb9a00f}\index{main.cpp@{main.cpp}!StopMotion\_Task@{StopMotion\_Task}}
\index{StopMotion\_Task@{StopMotion\_Task}!main.cpp@{main.cpp}}
\doxysubsubsection{\texorpdfstring{StopMotion\_Task()}{StopMotion\_Task()}}
{\footnotesize\ttfamily \label{main_8cpp_aab021fe7caed981cc28cbcd3ceb9a00f} 
void Stop\+Motion\+\_\+\+Task (\begin{DoxyParamCaption}\item[{void \texorpdfstring{$\ast$}{*}}]{pv\+Parameters}{}\end{DoxyParamCaption})}

\Hypertarget{main_8cpp_a5ca458d67906822bc0070de63d3bab8f}\index{main.cpp@{main.cpp}!telemetry\_Task@{telemetry\_Task}}
\index{telemetry\_Task@{telemetry\_Task}!main.cpp@{main.cpp}}
\doxysubsubsection{\texorpdfstring{telemetry\_Task()}{telemetry\_Task()}}
{\footnotesize\ttfamily \label{main_8cpp_a5ca458d67906822bc0070de63d3bab8f} 
void telemetry\+\_\+\+Task (\begin{DoxyParamCaption}\item[{void \texorpdfstring{$\ast$}{*}}]{pv\+Parameters}{}\end{DoxyParamCaption})}

\Hypertarget{main_8cpp_abde6d73b52e488a03bf8a31fddbeb554}\index{main.cpp@{main.cpp}!TrackingPredictor\_Task@{TrackingPredictor\_Task}}
\index{TrackingPredictor\_Task@{TrackingPredictor\_Task}!main.cpp@{main.cpp}}
\doxysubsubsection{\texorpdfstring{TrackingPredictor\_Task()}{TrackingPredictor\_Task()}}
{\footnotesize\ttfamily \label{main_8cpp_abde6d73b52e488a03bf8a31fddbeb554} 
void Tracking\+Predictor\+\_\+\+Task (\begin{DoxyParamCaption}\item[{void \texorpdfstring{$\ast$}{*}}]{pv\+Parameters}{}\end{DoxyParamCaption})}

\label{doc-var-members}
\Hypertarget{main_8cpp_doc-var-members}
\doxysubsection{Variable Documentation}
\Hypertarget{main_8cpp_a5f8db47b664833fcd348f6d72d7ff77e}\index{main.cpp@{main.cpp}!Calibration\_TaskHandle@{Calibration\_TaskHandle}}
\index{Calibration\_TaskHandle@{Calibration\_TaskHandle}!main.cpp@{main.cpp}}
\doxysubsubsection{\texorpdfstring{Calibration\_TaskHandle}{Calibration\_TaskHandle}}
{\footnotesize\ttfamily \label{main_8cpp_a5f8db47b664833fcd348f6d72d7ff77e} 
Task\+Handle\+\_\+t Calibration\+\_\+\+Task\+Handle = NULL}

\Hypertarget{main_8cpp_a95d592edb81dd40b1f9085628e7698a8}\index{main.cpp@{main.cpp}!config@{config}}
\index{config@{config}!main.cpp@{main.cpp}}
\doxysubsubsection{\texorpdfstring{config}{config}}
{\footnotesize\ttfamily \label{main_8cpp_a95d592edb81dd40b1f9085628e7698a8} 
Preferences config}

Global object for managing persistent configuration data (NVS). 

External reference to the global Preferences storage handler. \Hypertarget{main_8cpp_ac4a9a510f261e05b2f128b05c332b242}\index{main.cpp@{main.cpp}!controllerAz@{controllerAz}}
\index{controllerAz@{controllerAz}!main.cpp@{main.cpp}}
\doxysubsubsection{\texorpdfstring{controllerAz}{controllerAz}}
{\footnotesize\ttfamily \label{main_8cpp_ac4a9a510f261e05b2f128b05c332b242} 
\doxymbox{\hyperlink{class_p_i___controller}{PI\+\_\+\+Controller}} controller\+Az(\doxymbox{\hyperlink{configurations_8h_aeb86acb27e54b9755fcdac7881be9a67}{KP\+\_\+\+AZIMUTH}}, \doxymbox{\hyperlink{configurations_8h_a84c8a48add65471b6d7a3df86ded588a}{KI\+\_\+\+AZIMUTH}}, \doxymbox{\hyperlink{configurations_8h_a048e4fab329b80f602ac97b6aed12979}{SAMPLE\+\_\+\+TIME\+\_\+S}}, \doxymbox{\hyperlink{configurations_8h_af612d680313c8e405272d106245d0fe6}{M\+\_\+\+AZ\+\_\+\+V\+\_\+\+TO\+\_\+\+START}}, \doxymbox{\hyperlink{configurations_8h_a114551a5238cb0c6d988e55ba1d563c1}{M\+\_\+\+V\+\_\+\+NOMINAL}}) (\begin{DoxyParamCaption}\item[{\doxymbox{\hyperlink{configurations_8h_aeb86acb27e54b9755fcdac7881be9a67}{KP\+\_\+\+AZIMUTH}}}]{}{, }\item[{\doxymbox{\hyperlink{configurations_8h_a84c8a48add65471b6d7a3df86ded588a}{KI\+\_\+\+AZIMUTH}}}]{}{, }\item[{\doxymbox{\hyperlink{configurations_8h_a048e4fab329b80f602ac97b6aed12979}{SAMPLE\+\_\+\+TIME\+\_\+S}}}]{}{, }\item[{\doxymbox{\hyperlink{configurations_8h_af612d680313c8e405272d106245d0fe6}{M\+\_\+\+AZ\+\_\+\+V\+\_\+\+TO\+\_\+\+START}}}]{}{, }\item[{\doxymbox{\hyperlink{configurations_8h_a114551a5238cb0c6d988e55ba1d563c1}{M\+\_\+\+V\+\_\+\+NOMINAL}}}]{}{}\end{DoxyParamCaption})}

\Hypertarget{main_8cpp_a5373cc9382078d0e12734ddfe3d352c2}\index{main.cpp@{main.cpp}!controllerEl@{controllerEl}}
\index{controllerEl@{controllerEl}!main.cpp@{main.cpp}}
\doxysubsubsection{\texorpdfstring{controllerEl}{controllerEl}}
{\footnotesize\ttfamily \label{main_8cpp_a5373cc9382078d0e12734ddfe3d352c2} 
\doxymbox{\hyperlink{class_p_i___controller}{PI\+\_\+\+Controller}} controller\+El(\doxymbox{\hyperlink{configurations_8h_aa837cea21a670725c8482e7379c50b84}{KP\+\_\+\+ELEVATION}}, \doxymbox{\hyperlink{configurations_8h_a9f3f39cf87464e2b698790a8d22894d4}{KI\+\_\+\+ELEVATION}}, \doxymbox{\hyperlink{configurations_8h_a048e4fab329b80f602ac97b6aed12979}{SAMPLE\+\_\+\+TIME\+\_\+S}}, \doxymbox{\hyperlink{configurations_8h_afd517c26a46c866b3e18cf00c0e9b24b}{M\+\_\+\+EL\+\_\+\+V\+\_\+\+TO\+\_\+\+START}}, \doxymbox{\hyperlink{configurations_8h_a114551a5238cb0c6d988e55ba1d563c1}{M\+\_\+\+V\+\_\+\+NOMINAL}}) (\begin{DoxyParamCaption}\item[{\doxymbox{\hyperlink{configurations_8h_aa837cea21a670725c8482e7379c50b84}{KP\+\_\+\+ELEVATION}}}]{}{, }\item[{\doxymbox{\hyperlink{configurations_8h_a9f3f39cf87464e2b698790a8d22894d4}{KI\+\_\+\+ELEVATION}}}]{}{, }\item[{\doxymbox{\hyperlink{configurations_8h_a048e4fab329b80f602ac97b6aed12979}{SAMPLE\+\_\+\+TIME\+\_\+S}}}]{}{, }\item[{\doxymbox{\hyperlink{configurations_8h_afd517c26a46c866b3e18cf00c0e9b24b}{M\+\_\+\+EL\+\_\+\+V\+\_\+\+TO\+\_\+\+START}}}]{}{, }\item[{\doxymbox{\hyperlink{configurations_8h_a114551a5238cb0c6d988e55ba1d563c1}{M\+\_\+\+V\+\_\+\+NOMINAL}}}]{}{}\end{DoxyParamCaption})}

\Hypertarget{main_8cpp_a4bc81131529c2d9516c48205ad81ab20}\index{main.cpp@{main.cpp}!currentAz@{currentAz}}
\index{currentAz@{currentAz}!main.cpp@{main.cpp}}
\doxysubsubsection{\texorpdfstring{currentAz}{currentAz}}
{\footnotesize\ttfamily \label{main_8cpp_a4bc81131529c2d9516c48205ad81ab20} 
\doxymbox{\hyperlink{class_current_sensor}{Current\+Sensor}} current\+Az(\doxymbox{\hyperlink{configurations_8h_a4c9747a154da64ff447148d8d4fa5a20}{I\+\_\+\+AZ\+\_\+\+CHANNEL}}) (\begin{DoxyParamCaption}\item[{\doxymbox{\hyperlink{configurations_8h_a4c9747a154da64ff447148d8d4fa5a20}{I\+\_\+\+AZ\+\_\+\+CHANNEL}}}]{}{}\end{DoxyParamCaption})}

\Hypertarget{main_8cpp_a5bde5389f1e43c031d8188a5f6d5ae98}\index{main.cpp@{main.cpp}!currentEl@{currentEl}}
\index{currentEl@{currentEl}!main.cpp@{main.cpp}}
\doxysubsubsection{\texorpdfstring{currentEl}{currentEl}}
{\footnotesize\ttfamily \label{main_8cpp_a5bde5389f1e43c031d8188a5f6d5ae98} 
\doxymbox{\hyperlink{class_current_sensor}{Current\+Sensor}} current\+El(\doxymbox{\hyperlink{configurations_8h_a879a26029e799249e6786c5890d9f7e1}{I\+\_\+\+EL\+\_\+\+CHANNEL}}) (\begin{DoxyParamCaption}\item[{\doxymbox{\hyperlink{configurations_8h_a879a26029e799249e6786c5890d9f7e1}{I\+\_\+\+EL\+\_\+\+CHANNEL}}}]{}{}\end{DoxyParamCaption})}

\Hypertarget{main_8cpp_a13242e46cf88322a36d0a21f463814d6}\index{main.cpp@{main.cpp}!flags@{flags}}
\index{flags@{flags}!main.cpp@{main.cpp}}
\doxysubsubsection{\texorpdfstring{flags}{flags}}
{\footnotesize\ttfamily \label{main_8cpp_a13242e46cf88322a36d0a21f463814d6} 
\doxymbox{\hyperlink{utils_8h_a4e531e11ab017aad416f0432e33e1a31}{mount\+Flags\+\_\+t}} flags}

Global structure holding the current mount flags. 

\Hypertarget{main_8cpp_a169c53997a7da1d0fb99aec1b4675ce8}\index{main.cpp@{main.cpp}!gps@{gps}}
\index{gps@{gps}!main.cpp@{main.cpp}}
\doxysubsubsection{\texorpdfstring{gps}{gps}}
{\footnotesize\ttfamily \label{main_8cpp_a169c53997a7da1d0fb99aec1b4675ce8} 
Tiny\+GPSPlus gps}

\Hypertarget{main_8cpp_a31044d4fc6e109ea0df731c5e5c559ea}\index{main.cpp@{main.cpp}!GPS\_TaskHandle@{GPS\_TaskHandle}}
\index{GPS\_TaskHandle@{GPS\_TaskHandle}!main.cpp@{main.cpp}}
\doxysubsubsection{\texorpdfstring{GPS\_TaskHandle}{GPS\_TaskHandle}}
{\footnotesize\ttfamily \label{main_8cpp_a31044d4fc6e109ea0df731c5e5c559ea} 
Task\+Handle\+\_\+t GPS\+\_\+\+Task\+Handle = NULL}

\Hypertarget{main_8cpp_a128fc44694041af0e517137708eb73fb}\index{main.cpp@{main.cpp}!manualTargetAngle@{manualTargetAngle}}
\index{manualTargetAngle@{manualTargetAngle}!main.cpp@{main.cpp}}
\doxysubsubsection{\texorpdfstring{manualTargetAngle}{manualTargetAngle}}
{\footnotesize\ttfamily \label{main_8cpp_a128fc44694041af0e517137708eb73fb} 
\doxymbox{\hyperlink{utils_8h_aa27ea2fa6386a731820fdc8ed72ab361}{spherical\+Angles\+\_\+t}} manual\+Target\+Angle = \{0\}}

\Hypertarget{main_8cpp_aee44830b05e02ea9dd8829f08f3fbb8e}\index{main.cpp@{main.cpp}!MotionControl\_TaskHandle@{MotionControl\_TaskHandle}}
\index{MotionControl\_TaskHandle@{MotionControl\_TaskHandle}!main.cpp@{main.cpp}}
\doxysubsubsection{\texorpdfstring{MotionControl\_TaskHandle}{MotionControl\_TaskHandle}}
{\footnotesize\ttfamily \label{main_8cpp_aee44830b05e02ea9dd8829f08f3fbb8e} 
Task\+Handle\+\_\+t Motion\+Control\+\_\+\+Task\+Handle = NULL}

\Hypertarget{main_8cpp_a71c3efb3b6c68db64b67301de23c2c47}\index{main.cpp@{main.cpp}!motorAz@{motorAz}}
\index{motorAz@{motorAz}!main.cpp@{main.cpp}}
\doxysubsubsection{\texorpdfstring{motorAz}{motorAz}}
{\footnotesize\ttfamily \label{main_8cpp_a71c3efb3b6c68db64b67301de23c2c47} 
\doxymbox{\hyperlink{class_motor_driver}{Motor\+Driver}} motor\+Az(\doxymbox{\hyperlink{configurations_8h_a9ce983ce5b08d7846d8fa31118021b24}{IN1\+\_\+\+AZ\+\_\+\+PIN}}, \doxymbox{\hyperlink{configurations_8h_a9d57a6e7ffc17486374ef9dc813b76f4}{IN2\+\_\+\+AZ\+\_\+\+PIN}}, \doxymbox{\hyperlink{configurations_8h_ab18abfaf88f25a5ba352779defd5b333}{EN\+\_\+\+AZ\+\_\+\+PIN}}, LEDC\+\_\+\+TIMER\+\_\+0, LEDC\+\_\+\+CHANNEL\+\_\+0, \doxymbox{\hyperlink{configurations_8h_a56e165627f596c2f42f843ae6571de0e}{PWM\+\_\+\+FREQ\+\_\+\+HZ}}) (\begin{DoxyParamCaption}\item[{\doxymbox{\hyperlink{configurations_8h_a9ce983ce5b08d7846d8fa31118021b24}{IN1\+\_\+\+AZ\+\_\+\+PIN}}}]{}{, }\item[{\doxymbox{\hyperlink{configurations_8h_a9d57a6e7ffc17486374ef9dc813b76f4}{IN2\+\_\+\+AZ\+\_\+\+PIN}}}]{}{, }\item[{\doxymbox{\hyperlink{configurations_8h_ab18abfaf88f25a5ba352779defd5b333}{EN\+\_\+\+AZ\+\_\+\+PIN}}}]{}{, }\item[{LEDC\+\_\+\+TIMER\+\_\+0}]{}{, }\item[{LEDC\+\_\+\+CHANNEL\+\_\+0}]{}{, }\item[{\doxymbox{\hyperlink{configurations_8h_a56e165627f596c2f42f843ae6571de0e}{PWM\+\_\+\+FREQ\+\_\+\+HZ}}}]{}{}\end{DoxyParamCaption})}

\Hypertarget{main_8cpp_a75ce768f93f1fd4332896623d2635209}\index{main.cpp@{main.cpp}!motorEl@{motorEl}}
\index{motorEl@{motorEl}!main.cpp@{main.cpp}}
\doxysubsubsection{\texorpdfstring{motorEl}{motorEl}}
{\footnotesize\ttfamily \label{main_8cpp_a75ce768f93f1fd4332896623d2635209} 
\doxymbox{\hyperlink{class_motor_driver}{Motor\+Driver}} motor\+El(\doxymbox{\hyperlink{configurations_8h_a2f5dd98516c40e68c6da603ddcab8698}{IN1\+\_\+\+EL\+\_\+\+PIN}}, \doxymbox{\hyperlink{configurations_8h_a3c8358b42b349a816f9ef990377fd98b}{IN2\+\_\+\+EL\+\_\+\+PIN}}, \doxymbox{\hyperlink{configurations_8h_a48348f346a55b4cdd6249e8d8491242d}{EN\+\_\+\+EL\+\_\+\+PIN}}, LEDC\+\_\+\+TIMER\+\_\+0, LEDC\+\_\+\+CHANNEL\+\_\+1, \doxymbox{\hyperlink{configurations_8h_a56e165627f596c2f42f843ae6571de0e}{PWM\+\_\+\+FREQ\+\_\+\+HZ}}) (\begin{DoxyParamCaption}\item[{\doxymbox{\hyperlink{configurations_8h_a2f5dd98516c40e68c6da603ddcab8698}{IN1\+\_\+\+EL\+\_\+\+PIN}}}]{}{, }\item[{\doxymbox{\hyperlink{configurations_8h_a3c8358b42b349a816f9ef990377fd98b}{IN2\+\_\+\+EL\+\_\+\+PIN}}}]{}{, }\item[{\doxymbox{\hyperlink{configurations_8h_a48348f346a55b4cdd6249e8d8491242d}{EN\+\_\+\+EL\+\_\+\+PIN}}}]{}{, }\item[{LEDC\+\_\+\+TIMER\+\_\+0}]{}{, }\item[{LEDC\+\_\+\+CHANNEL\+\_\+1}]{}{, }\item[{\doxymbox{\hyperlink{configurations_8h_a56e165627f596c2f42f843ae6571de0e}{PWM\+\_\+\+FREQ\+\_\+\+HZ}}}]{}{}\end{DoxyParamCaption})}

\Hypertarget{main_8cpp_a7612bbada92b5c10ddfcd3e5251e258b}\index{main.cpp@{main.cpp}!mountAngle@{mountAngle}}
\index{mountAngle@{mountAngle}!main.cpp@{main.cpp}}
\doxysubsubsection{\texorpdfstring{mountAngle}{mountAngle}}
{\footnotesize\ttfamily \label{main_8cpp_a7612bbada92b5c10ddfcd3e5251e258b} 
\doxymbox{\hyperlink{utils_8h_aa27ea2fa6386a731820fdc8ed72ab361}{spherical\+Angles\+\_\+t}} mount\+Angle = \{0\}}

Global structure for the current (measured) antenna position. 

\Hypertarget{main_8cpp_a46e1484ba8c7792f044d44dc3e9594c4}\index{main.cpp@{main.cpp}!nextPass\_unix@{nextPass\_unix}}
\index{nextPass\_unix@{nextPass\_unix}!main.cpp@{main.cpp}}
\doxysubsubsection{\texorpdfstring{nextPass\_unix}{nextPass\_unix}}
{\footnotesize\ttfamily \label{main_8cpp_a46e1484ba8c7792f044d44dc3e9594c4} 
unsigned long next\+Pass\+\_\+unix = 0}

Next pass start time in unix. 

\Hypertarget{main_8cpp_a64f04e683eecc9224b4e930d088f89fb}\index{main.cpp@{main.cpp}!offsetAngle@{offsetAngle}}
\index{offsetAngle@{offsetAngle}!main.cpp@{main.cpp}}
\doxysubsubsection{\texorpdfstring{offsetAngle}{offsetAngle}}
{\footnotesize\ttfamily \label{main_8cpp_a64f04e683eecc9224b4e930d088f89fb} 
\doxymbox{\hyperlink{utils_8h_aa27ea2fa6386a731820fdc8ed72ab361}{spherical\+Angles\+\_\+t}} offset\+Angle = \{0\}}

\Hypertarget{main_8cpp_a2c5a73a4c30d5441190eb5440c7d971b}\index{main.cpp@{main.cpp}!reedAz@{reedAz}}
\index{reedAz@{reedAz}!main.cpp@{main.cpp}}
\doxysubsubsection{\texorpdfstring{reedAz}{reedAz}}
{\footnotesize\ttfamily \label{main_8cpp_a2c5a73a4c30d5441190eb5440c7d971b} 
\doxymbox{\hyperlink{class_reed_switch}{Reed\+Switch}} reed\+Az(\doxymbox{\hyperlink{configurations_8h_aa87d687897e717dea73184063e2b3be1}{REED\+\_\+\+AZ\+\_\+\+PIN}}, PCNT\+\_\+\+UNIT\+\_\+0, PCNT\+\_\+\+CHANNEL\+\_\+0, \doxymbox{\hyperlink{configurations_8h_acdaca90d9569b370599f231928e32845}{REED\+\_\+\+AZ\+\_\+\+SOFT\+\_\+\+LIMIT\+\_\+\+LOW}}, \doxymbox{\hyperlink{configurations_8h_a9fc5bef92112470db8255986b6ecebcb}{REED\+\_\+\+AZ\+\_\+\+SOFT\+\_\+\+LIMIT\+\_\+\+HIGH}}, \doxymbox{\hyperlink{main_8cpp_a1dd4b93df00922d511a5f6925175bc6a}{reed\+Az\+\_\+event\+\_\+handler}}) (\begin{DoxyParamCaption}\item[{\doxymbox{\hyperlink{configurations_8h_aa87d687897e717dea73184063e2b3be1}{REED\+\_\+\+AZ\+\_\+\+PIN}}}]{}{, }\item[{PCNT\+\_\+\+UNIT\+\_\+0}]{}{, }\item[{PCNT\+\_\+\+CHANNEL\+\_\+0}]{}{, }\item[{\doxymbox{\hyperlink{configurations_8h_acdaca90d9569b370599f231928e32845}{REED\+\_\+\+AZ\+\_\+\+SOFT\+\_\+\+LIMIT\+\_\+\+LOW}}}]{}{, }\item[{\doxymbox{\hyperlink{configurations_8h_a9fc5bef92112470db8255986b6ecebcb}{REED\+\_\+\+AZ\+\_\+\+SOFT\+\_\+\+LIMIT\+\_\+\+HIGH}}}]{}{, }\item[{\doxymbox{\hyperlink{main_8cpp_a1dd4b93df00922d511a5f6925175bc6a}{reed\+Az\+\_\+event\+\_\+handler}}}]{}{}\end{DoxyParamCaption})}

\Hypertarget{main_8cpp_a32c123ba4604b420b78493bc54f3ede4}\index{main.cpp@{main.cpp}!reedEl@{reedEl}}
\index{reedEl@{reedEl}!main.cpp@{main.cpp}}
\doxysubsubsection{\texorpdfstring{reedEl}{reedEl}}
{\footnotesize\ttfamily \label{main_8cpp_a32c123ba4604b420b78493bc54f3ede4} 
\doxymbox{\hyperlink{class_reed_switch}{Reed\+Switch}} reed\+El(\doxymbox{\hyperlink{configurations_8h_ac623bf5b9b1b5e841f3d5358f5ce36f7}{REED\+\_\+\+EL\+\_\+\+PIN}}, PCNT\+\_\+\+UNIT\+\_\+1, PCNT\+\_\+\+CHANNEL\+\_\+0, \doxymbox{\hyperlink{configurations_8h_a08a68068b1a658d3b0e967b799a84100}{REED\+\_\+\+EL\+\_\+\+SOFT\+\_\+\+LIMIT\+\_\+\+LOW}}, \doxymbox{\hyperlink{configurations_8h_a7de64bbb117e66e561add80d7f24374e}{REED\+\_\+\+EL\+\_\+\+SOFT\+\_\+\+LIMIT\+\_\+\+HIGH}}, \doxymbox{\hyperlink{main_8cpp_ab8fa2c4464e56c5bc776469aadd26360}{reed\+El\+\_\+event\+\_\+handler}}) (\begin{DoxyParamCaption}\item[{\doxymbox{\hyperlink{configurations_8h_ac623bf5b9b1b5e841f3d5358f5ce36f7}{REED\+\_\+\+EL\+\_\+\+PIN}}}]{}{, }\item[{PCNT\+\_\+\+UNIT\+\_\+1}]{}{, }\item[{PCNT\+\_\+\+CHANNEL\+\_\+0}]{}{, }\item[{\doxymbox{\hyperlink{configurations_8h_a08a68068b1a658d3b0e967b799a84100}{REED\+\_\+\+EL\+\_\+\+SOFT\+\_\+\+LIMIT\+\_\+\+LOW}}}]{}{, }\item[{\doxymbox{\hyperlink{configurations_8h_a7de64bbb117e66e561add80d7f24374e}{REED\+\_\+\+EL\+\_\+\+SOFT\+\_\+\+LIMIT\+\_\+\+HIGH}}}]{}{, }\item[{\doxymbox{\hyperlink{main_8cpp_ab8fa2c4464e56c5bc776469aadd26360}{reed\+El\+\_\+event\+\_\+handler}}}]{}{}\end{DoxyParamCaption})}

\Hypertarget{main_8cpp_a7a8e6488a647b64ac7902070f7d3a373}\index{main.cpp@{main.cpp}!satellite@{satellite}}
\index{satellite@{satellite}!main.cpp@{main.cpp}}
\doxysubsubsection{\texorpdfstring{satellite}{satellite}}
{\footnotesize\ttfamily \label{main_8cpp_a7a8e6488a647b64ac7902070f7d3a373} 
Sgp4 satellite}

Global SGP4 object for satellite orbit prediction. 

\Hypertarget{main_8cpp_a30f0d942420b66dee65de9c062b2466b}\index{main.cpp@{main.cpp}!serverHandler@{serverHandler}}
\index{serverHandler@{serverHandler}!main.cpp@{main.cpp}}
\doxysubsubsection{\texorpdfstring{serverHandler}{serverHandler}}
{\footnotesize\ttfamily \label{main_8cpp_a30f0d942420b66dee65de9c062b2466b} 
\doxymbox{\hyperlink{class_server_handler}{Server\+Handler}} server\+Handler(\doxymbox{\hyperlink{configurations_8h_af257e2a3e091629829857a2eb8931a7a}{DEFAULT\+\_\+\+SERVER\+\_\+\+PORT}}) (\begin{DoxyParamCaption}\item[{\doxymbox{\hyperlink{configurations_8h_af257e2a3e091629829857a2eb8931a7a}{DEFAULT\+\_\+\+SERVER\+\_\+\+PORT}}}]{}{}\end{DoxyParamCaption})}

\Hypertarget{main_8cpp_a47f50d5a92efa4cb35b7c0e5e247cb27}\index{main.cpp@{main.cpp}!setPointAngle@{setPointAngle}}
\index{setPointAngle@{setPointAngle}!main.cpp@{main.cpp}}
\doxysubsubsection{\texorpdfstring{setPointAngle}{setPointAngle}}
{\footnotesize\ttfamily \label{main_8cpp_a47f50d5a92efa4cb35b7c0e5e247cb27} 
\doxymbox{\hyperlink{utils_8h_aa27ea2fa6386a731820fdc8ed72ab361}{spherical\+Angles\+\_\+t}} set\+Point\+Angle = \{0\}}

\Hypertarget{main_8cpp_abb195f07774e5b37386632d27be9fcfd}\index{main.cpp@{main.cpp}!sgp4TargetAngle@{sgp4TargetAngle}}
\index{sgp4TargetAngle@{sgp4TargetAngle}!main.cpp@{main.cpp}}
\doxysubsubsection{\texorpdfstring{sgp4TargetAngle}{sgp4TargetAngle}}
{\footnotesize\ttfamily \label{main_8cpp_abb195f07774e5b37386632d27be9fcfd} 
\doxymbox{\hyperlink{utils_8h_aa27ea2fa6386a731820fdc8ed72ab361}{spherical\+Angles\+\_\+t}} sgp4\+Target\+Angle = \{0\}}

Global structure for the target (commanded) antenna position. 

\Hypertarget{main_8cpp_ae231754aa856e7e4956e423e1b308ee9}\index{main.cpp@{main.cpp}!status@{status}}
\index{status@{status}!main.cpp@{main.cpp}}
\doxysubsubsection{\texorpdfstring{status}{status}}
{\footnotesize\ttfamily \label{main_8cpp_ae231754aa856e7e4956e423e1b308ee9} 
\doxymbox{\hyperlink{utils_8h_af8a35661022926a438bb0e33cf4e84d2}{tracker\+Status\+\_\+t}} status}

Global structure holding the current operational status of the tracker. 

\Hypertarget{main_8cpp_a76bda418f1aad970979562c0a0d5ecd4}\index{main.cpp@{main.cpp}!StopMotion\_TaskHandle@{StopMotion\_TaskHandle}}
\index{StopMotion\_TaskHandle@{StopMotion\_TaskHandle}!main.cpp@{main.cpp}}
\doxysubsubsection{\texorpdfstring{StopMotion\_TaskHandle}{StopMotion\_TaskHandle}}
{\footnotesize\ttfamily \label{main_8cpp_a76bda418f1aad970979562c0a0d5ecd4} 
Task\+Handle\+\_\+t Stop\+Motion\+\_\+\+Task\+Handle = NULL}

\Hypertarget{main_8cpp_a5a85b9c772bbeb480b209a3e6ea92b4c}\index{main.cpp@{main.cpp}!TAG@{TAG}}
\index{TAG@{TAG}!main.cpp@{main.cpp}}
\doxysubsubsection{\texorpdfstring{TAG}{TAG}}
{\footnotesize\ttfamily \label{main_8cpp_a5a85b9c772bbeb480b209a3e6ea92b4c} 
const char\texorpdfstring{$\ast$}{*} TAG = "{}MAIN"{}\hspace{0.3cm}{\ttfamily [static]}}

\Hypertarget{main_8cpp_a00ee04c34be775944fa477ad9d975031}\index{main.cpp@{main.cpp}!targetAngle@{targetAngle}}
\index{targetAngle@{targetAngle}!main.cpp@{main.cpp}}
\doxysubsubsection{\texorpdfstring{targetAngle}{targetAngle}}
{\footnotesize\ttfamily \label{main_8cpp_a00ee04c34be775944fa477ad9d975031} 
\doxymbox{\hyperlink{utils_8h_aa27ea2fa6386a731820fdc8ed72ab361}{spherical\+Angles\+\_\+t}} target\+Angle = \{0\}}

\Hypertarget{main_8cpp_abefc65e0e269b258dd4ed3f4c340658a}\index{main.cpp@{main.cpp}!TrackingPredictor\_TaskHandle@{TrackingPredictor\_TaskHandle}}
\index{TrackingPredictor\_TaskHandle@{TrackingPredictor\_TaskHandle}!main.cpp@{main.cpp}}
\doxysubsubsection{\texorpdfstring{TrackingPredictor\_TaskHandle}{TrackingPredictor\_TaskHandle}}
{\footnotesize\ttfamily \label{main_8cpp_abefc65e0e269b258dd4ed3f4c340658a} 
Task\+Handle\+\_\+t Tracking\+Predictor\+\_\+\+Task\+Handle = NULL}

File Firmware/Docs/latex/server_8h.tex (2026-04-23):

\doxysection{include/\+server.h File Reference}
\hypertarget{server_8h}{}\label{server_8h}\index{include/server.h@{include/server.h}}
{\ttfamily \+\#include $<$Wi\+Fi.\+h$>$}\newline
{\ttfamily \+\#include $<$ESPm\+DNS.\+h$>$}\newline
{\ttfamily \+\#include $<$ESPAsync\+Web\+Server.\+h$>$}\newline
{\ttfamily \+\#include $<$Arduino\+Json.\+h$>$}\newline
{\ttfamily \+\#include $<$Preferences.\+h$>$}\newline
{\ttfamily \+\#include $<$Sgp4.\+h$>$}\newline
{\ttfamily \+\#include $<$SPIFFS.\+h$>$}\newline
{\ttfamily \+\#include $<$sys/\+time.\+h$>$}\newline
{\ttfamily \+\#include "{}utils.\+h"{}}\newline
{\ttfamily \+\#include "{}configurations.\+h"{}}\newline
{\ttfamily \+\#include "{}esp\+\_\+log.\+h"{}}\newline
{\ttfamily \+\#include "{}esp\+\_\+err.\+h"{}}\newline
\doxysubsubsection*{Classes}
\begin{DoxyCompactItemize}
\item 
class \doxymbox{\hyperlink{class_server_handler}{Server\+Handler}}
\begin{DoxyCompactList}\small\item\em Manages the ESP32\textquotesingle{}s asynchronous web server, handles API requests, and serves configuration/\+status data. \end{DoxyCompactList}\end{DoxyCompactItemize}
\doxysubsubsection*{Variables}
\begin{DoxyCompactItemize}
\item 
Sgp4 \doxymbox{\hyperlink{server_8h_a7a8e6488a647b64ac7902070f7d3a373}{satellite}}
\begin{DoxyCompactList}\small\item\em Global SGP4 object for satellite orbit prediction. \end{DoxyCompactList}\item 
Preferences \doxymbox{\hyperlink{server_8h_a95d592edb81dd40b1f9085628e7698a8}{config}}
\begin{DoxyCompactList}\small\item\em Global object for managing persistent configuration data (NVS). \end{DoxyCompactList}\item 
\doxymbox{\hyperlink{utils_8h_af8a35661022926a438bb0e33cf4e84d2}{tracker\+Status\+\_\+t}} \doxymbox{\hyperlink{server_8h_ae231754aa856e7e4956e423e1b308ee9}{status}}
\begin{DoxyCompactList}\small\item\em Global structure holding the current operational status of the tracker. \end{DoxyCompactList}\item 
\doxymbox{\hyperlink{utils_8h_a4e531e11ab017aad416f0432e33e1a31}{mount\+Flags\+\_\+t}} \doxymbox{\hyperlink{server_8h_a13242e46cf88322a36d0a21f463814d6}{flags}}
\begin{DoxyCompactList}\small\item\em Global structure holding the current mount flags. \end{DoxyCompactList}\item 
\doxymbox{\hyperlink{utils_8h_aa27ea2fa6386a731820fdc8ed72ab361}{spherical\+Angles\+\_\+t}} \doxymbox{\hyperlink{server_8h_abb195f07774e5b37386632d27be9fcfd}{sgp4\+Target\+Angle}}
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

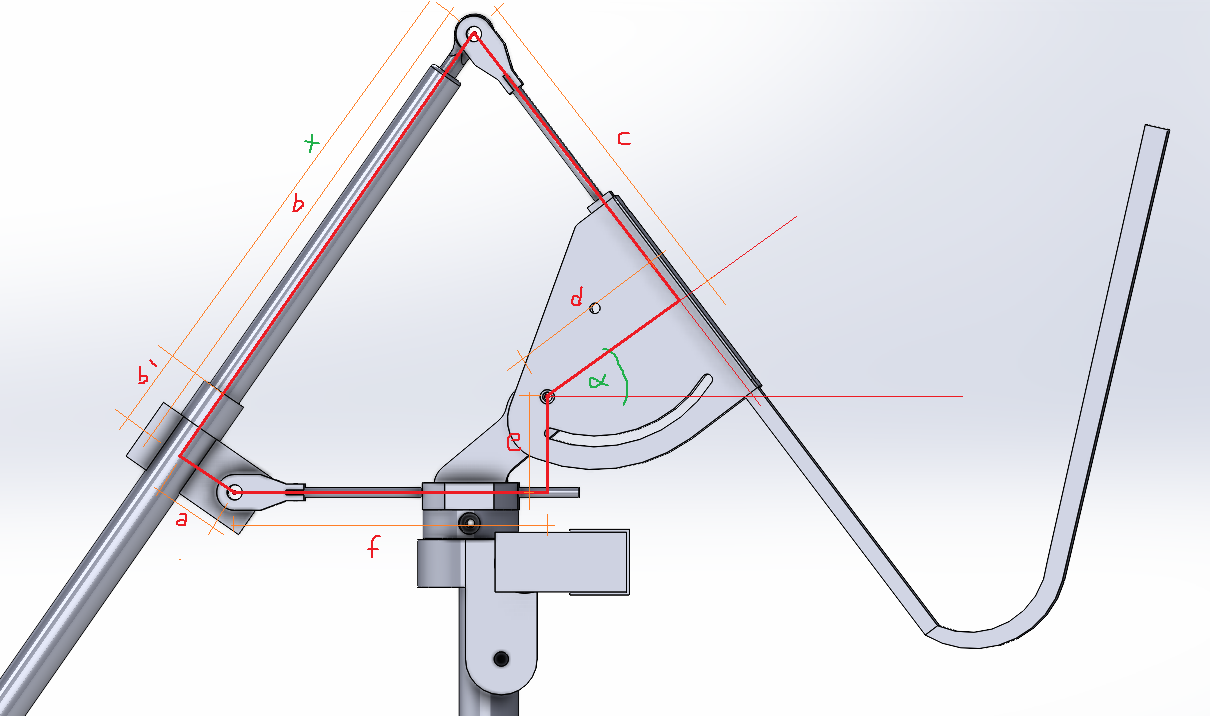
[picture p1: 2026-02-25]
Hardware/Dimensiones.png

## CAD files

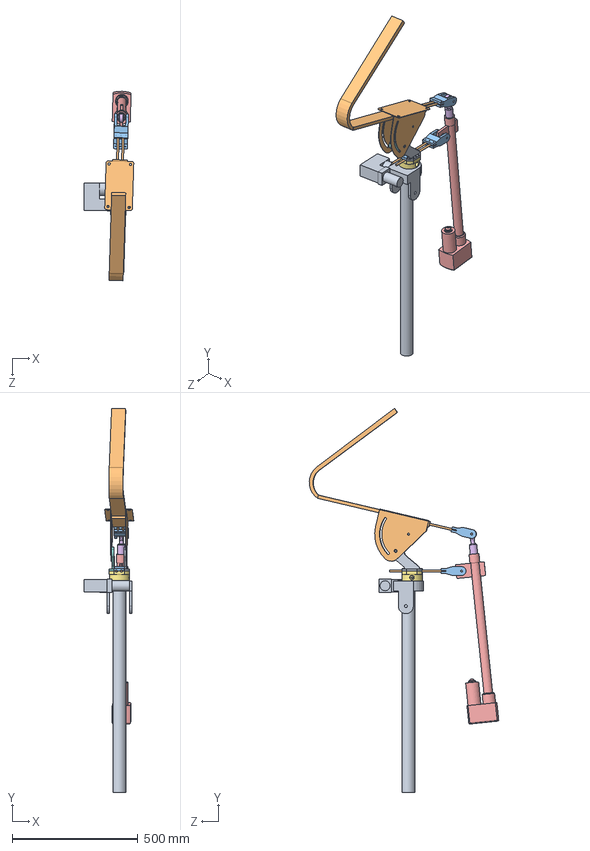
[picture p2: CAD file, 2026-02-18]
Hardware/Piezas/Montura/Ensamblaje1.SLDASM
196.8 x 1525.1 x 752.8 mm
ActRotacional
barra x 4
TAPA
GUIA
ActLineal1
ActLineal2
BASE
PARED_R
PARED_L
PLATAFORMA_PARABOLICA
EJE_REFORZADO x 2

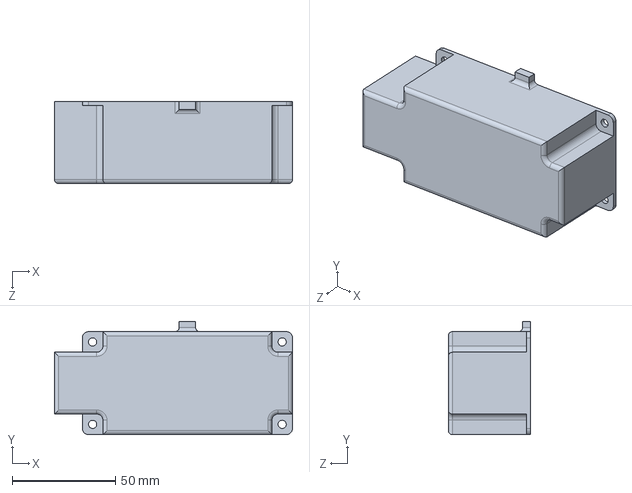
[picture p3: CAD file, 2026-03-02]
Hardware/Piezas/CajaEstanca/TapaAzimut.SLDPRT
115.5 x 55.0 x 40.0 mm

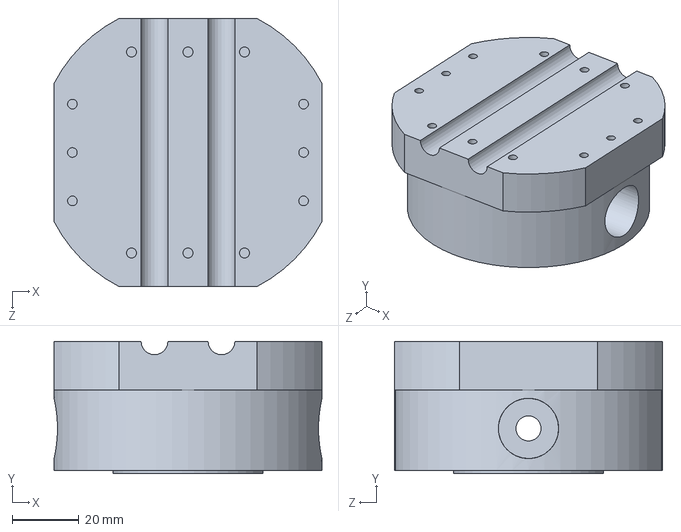
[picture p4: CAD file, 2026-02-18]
Hardware/Piezas/Montura/BaseAzimut.SLDPRT
80.0 x 39.5 x 80.0 mm

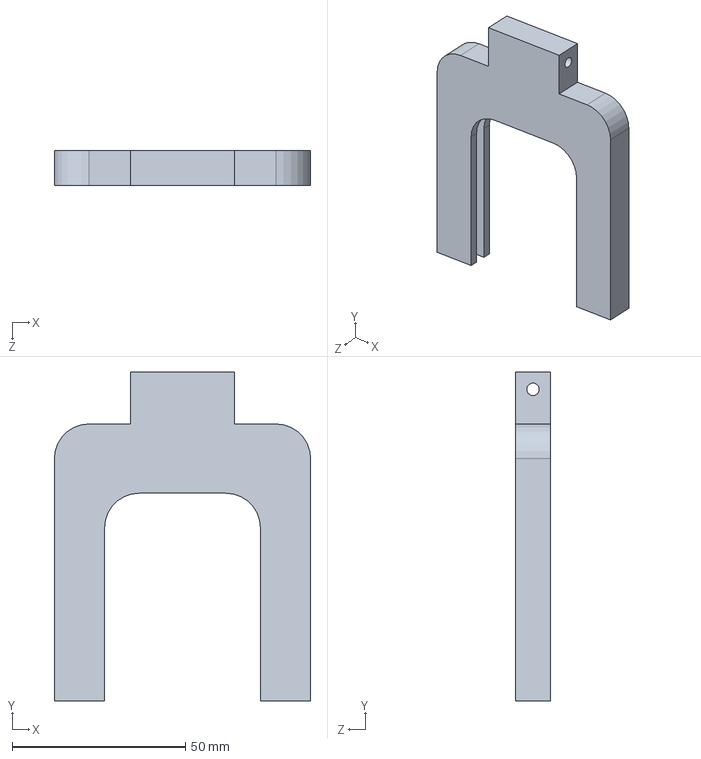
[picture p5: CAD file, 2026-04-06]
Hardware/Piezas/Otros/AgarreCompas/compas.SLDPRT
74.0 x 95.0 x 10.0 mm

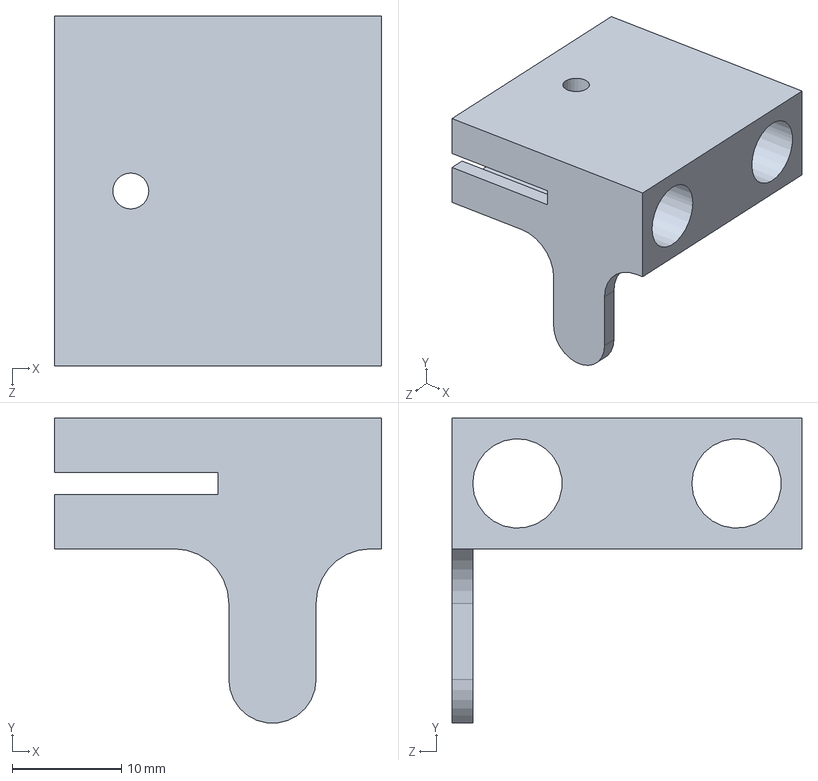
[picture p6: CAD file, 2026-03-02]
Hardware/Piezas/Otros/FinalCarreraAzimut/TopeFinalCarrera.SLDPRT
30.0 x 28.0 x 32.1 mm

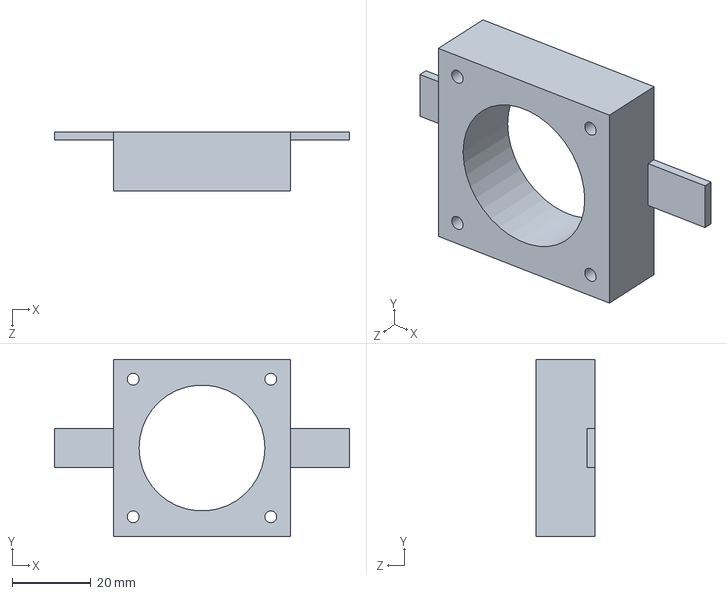
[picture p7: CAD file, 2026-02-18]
Hardware/Piezas/Otros/MediciónAzimut/AgarreBase.SLDPRT
75.0 x 45.0 x 15.0 mm

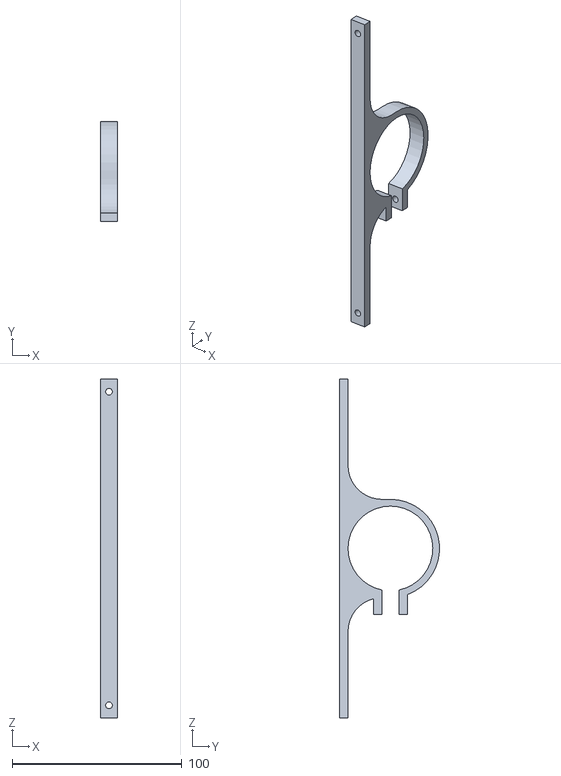
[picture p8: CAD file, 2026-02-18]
Hardware/Piezas/CajaEstanca/AgarreCajaEscanta.STL
10.0 x 58.9 x 200.0

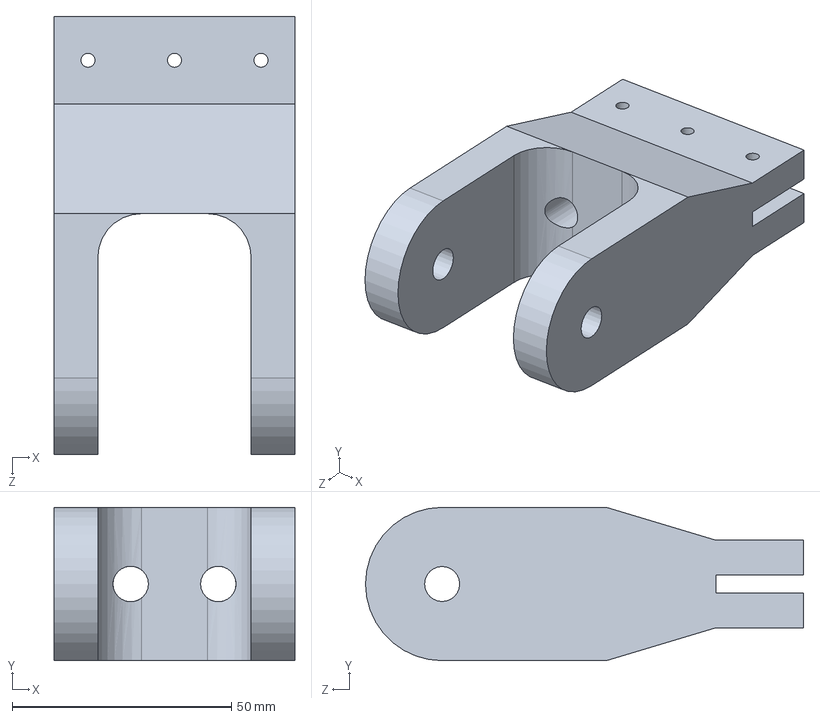
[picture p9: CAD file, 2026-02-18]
Hardware/Piezas/Montura/EjeActuadorElevación.SLDPRT
55.0 x 35.0 x 100.0 mm

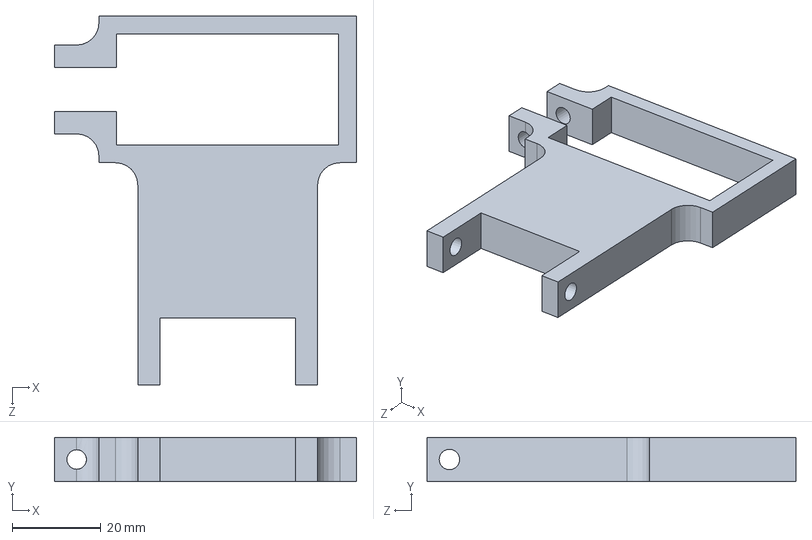
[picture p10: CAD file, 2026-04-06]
Hardware/Piezas/Otros/AgarreCompas/compas2.SLDPRT
68.0 x 10.0 x 83.0 mm

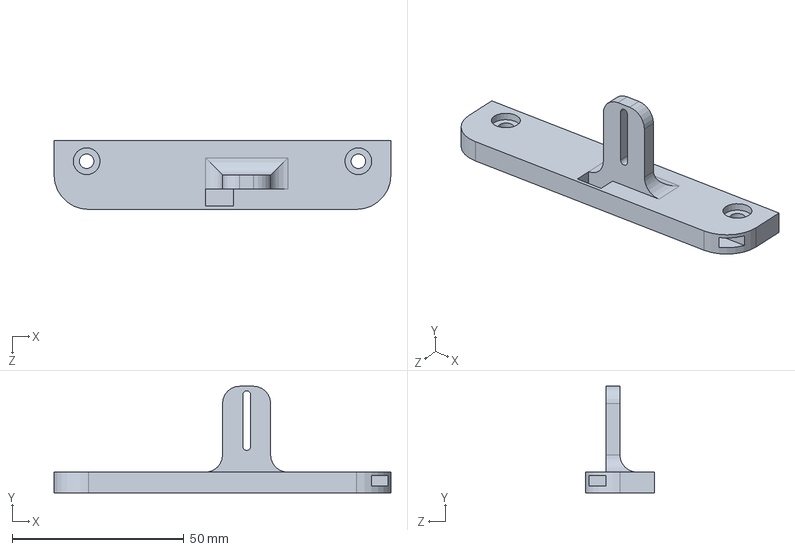
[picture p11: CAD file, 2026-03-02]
Hardware/Piezas/Otros/FinalCarreraAzimut/BaseFinalCarrera.SLDPRT
98.0 x 31.0 x 20.0 mm

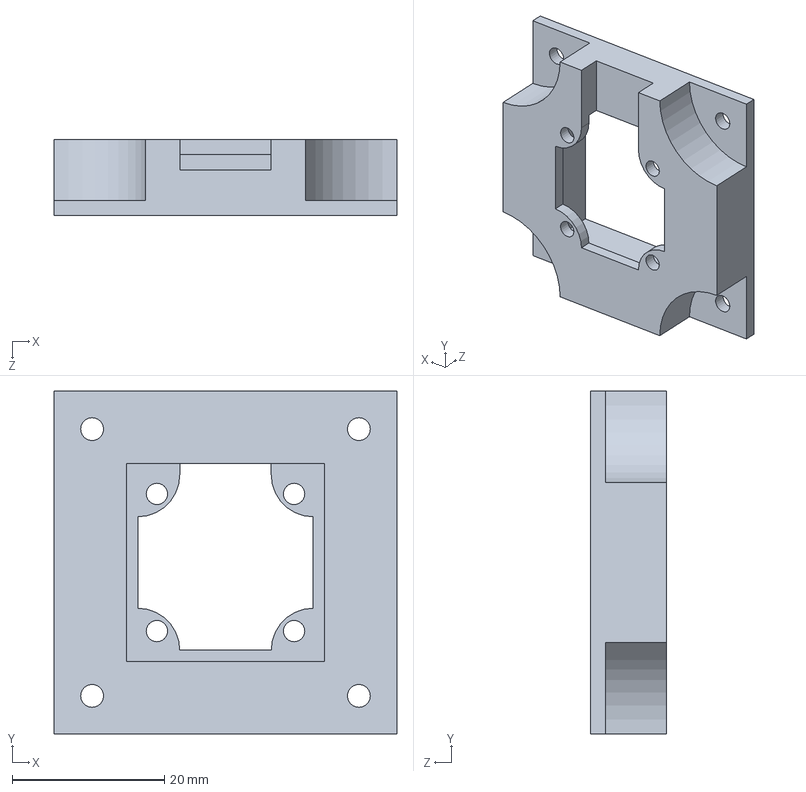
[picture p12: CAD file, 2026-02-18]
Hardware/Piezas/Otros/MediciónAzimut/AgarreMT6701.SLDPRT
45.0 x 45.0 x 10.0 mm

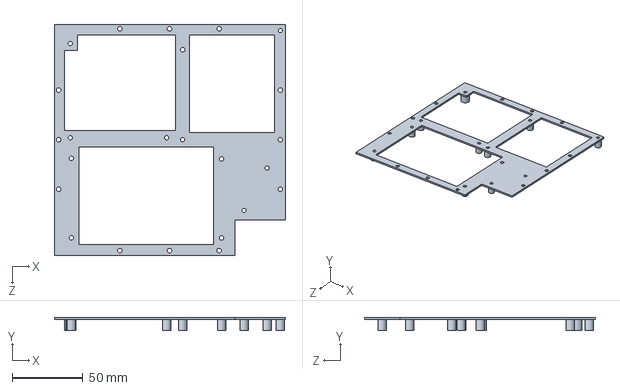
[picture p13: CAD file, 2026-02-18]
Hardware/Piezas/CajaEstanca/MonturaElectronica.SLDPRT
163.0 x 9.10 x 163.0 mm

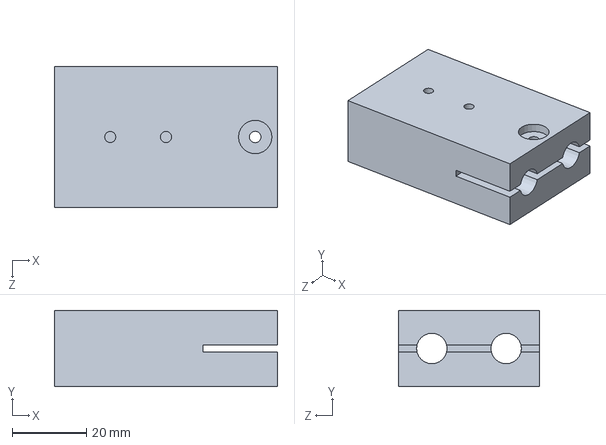
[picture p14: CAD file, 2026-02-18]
Hardware/Piezas/Montura/GuíaBaseParábola.SLDPRT
60.0 x 20.5 x 38.0 mm

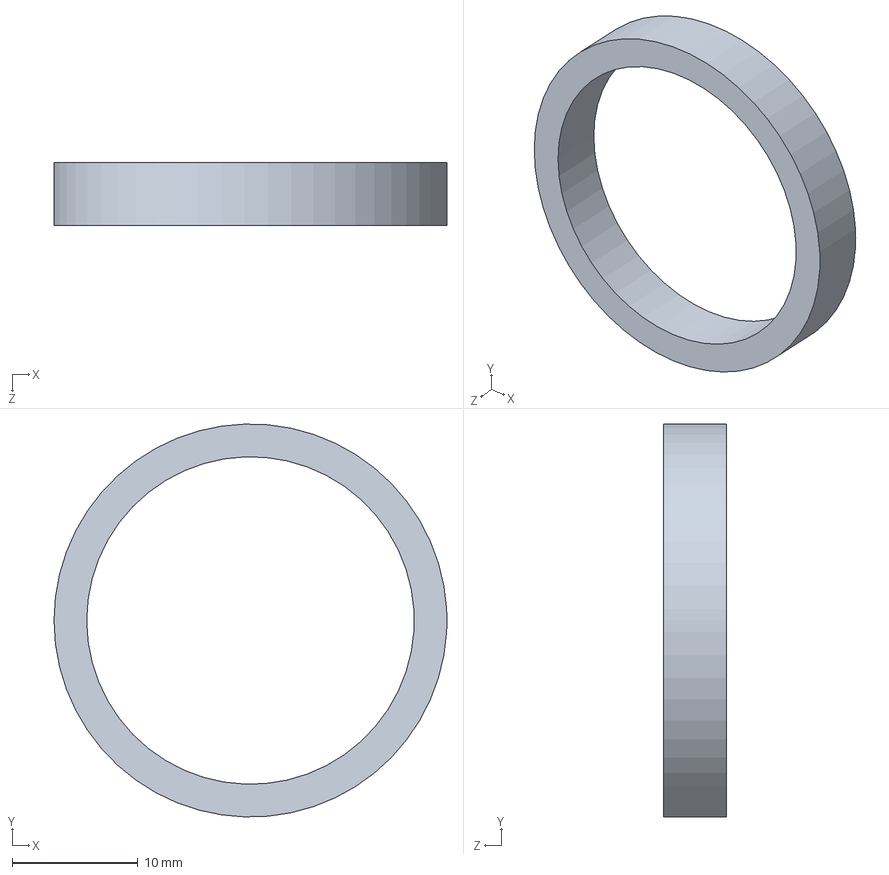
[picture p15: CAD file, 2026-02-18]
Hardware/Piezas/Otros/MediciónAzimut/span.SLDPRT
31.2 x 31.2 x 5.00 mm

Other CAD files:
Hardware/Piezas/CajaEstanca/AgarreCajaEstanca.SLDPRT
Hardware/Piezas/Montura/ActRotacional.SLDPRT
Hardware/Piezas/Otros/MediciónAzimut/EjeImán.SLDPRT
Hardware/Piezas/CajaEstanca/EspaciadorCables.SLDPRT
Hardware/Piezas/CajaEstanca/EspaciadorCables.STL
Hardware/Piezas/CajaEstanca/MonturaElectronica.STL
Hardware/Piezas/CajaEstanca/TapaAzimut.STL
Hardware/Piezas/Montura/ActLineal1.SLDPRT
Hardware/Piezas/Montura/ActLineal2.SLDPRT
Hardware/Piezas/Montura/BaseAzimut.STL
Hardware/Piezas/Montura/BaseParábola.SLDPRT
Hardware/Piezas/Montura/EjeActuadorElevación.STL
Hardware/Piezas/Montura/GuíaBaseParábola.STL
Hardware/Piezas/Montura/ParedL.SLDPRT
Hardware/Piezas/Montura/ParedL.STL
Hardware/Piezas/Montura/ParedR.SLDPRT
Hardware/Piezas/Montura/ParedR.STL
Hardware/Piezas/Montura/TapaBase.SLDPRT
Hardware/Piezas/Montura/TapaBase.STL
Hardware/Piezas/Montura/barra.SLDPRT
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

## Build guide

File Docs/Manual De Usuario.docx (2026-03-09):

# Manual de Instrucciones Montura Motorizada para Seguimiento Satelital

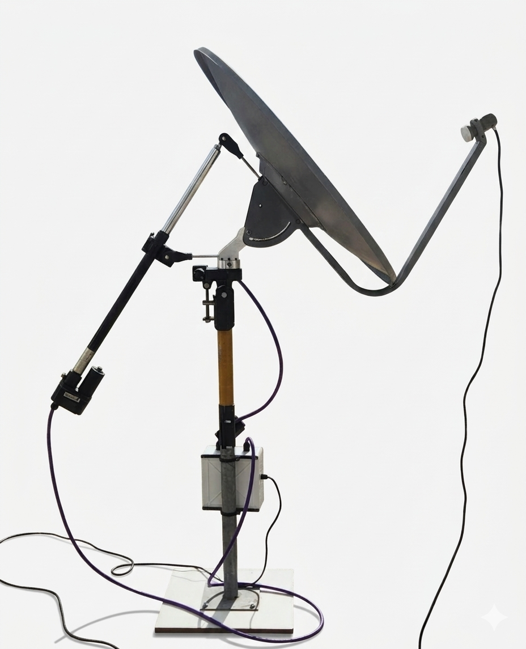
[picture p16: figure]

INTRODUCCIÓN

El dispositivo se trata de un sistema de rastreo automático de satélites de órbita baja (LEO), satélites geoestacionarios (GEO) e incluso satélites de órbita media (MEO); Consta de una montura del tipo Azimut-Elevación no apta para su instalación geográfica cercana al ecuador debido a su dificultad para realizar maniobras cercanas al cenit.

SEGURIDAD

- Encontrarse alejado del dispositivo durante su funcionamiento.
- Instalar el dispositivo en un lugar seguro alejado de elementos peligrosos y procurando su movilidad sin obstrucciones.
- La montura no está diseñada para su uso con cargas de vientos elevadas.

USABILIDAD

El dispositivo puede ser configurado para el seguimiento satelital conectándose a la red WiFi generada en modo AP (Access Point) por el mismo. Al ingresar en su navegador la URL http://tracker.local ud. será dirigido a la página principal del dispositivo, donde encontrará información acerca de la telemetría del sistema de seguimiento.

Descripción de los datos de telemetría:

Los datos acerca del satélite y la plataforma son actualizados cada segundo automáticamente, en este apartado encontrará:

Satélite
Dato | Descripción | Unidad
ID | Identificación del satélite (Nombre) | -
Latitud | Posición norte-sur respecto al ecuador del punto sub-satélite | Grados
Longitud | Posición este-oeste del punto sub-satélite | Grados
Altitud | Altura respecto de la superficie terrestre y el satélite | Kilómetros
Azimut (Θ) | Ángulo horizontal de apuntamiento medido desde el norte geográfico en sentido horario calculado desde la ubicación de la plataforma con el modelo SGP4 | grados
Elevación (ɑ) | Ángulo vertical medido desde el horizonte desde la ubicación de la plataforma con el modelo SGP4 | Grados
Visibilidad | Nivel de visibilidad del satélite (Iluminado-Eclipse-Penumbra-No visible) | -
Siguiente Pase | Fecha y Hora predecida al cual el satélite saldrá del horizonte (Depende del offset configurado para la antena) | DD:MM:AAAA, HH:MM:SS

Estación Terrena
Dato | Descripción | Unidad
Estado | Detenido, Trackeando, Error,... | -
Latitud | Posición norte-sur respecto al ecuador de la montura | Grados
Longitud | Posición este-oeste de la montura | Grados
Altitud | Altura respecto del nivel del mar | Kilómetros
Hora Local | Tiempo actual de la estación terrena | DD:MM:AAAA, HH:MM:SS

Antena
Dato | Descripción | Unidad
Azimut (Θ) | Ángulo horizontal actual respecto de la plataforma (Con los desplazamientos configurados) | Grados
Elevación (ɑ) | Ángulo vertical actual respecto de la plataforma (Con los desplazamientos configurados) | Grados
Offset Azimut | Desplazamiento actual configurado respecto del ángulo horizontal, (entre la montura y la antena) | Grados
Offset Elevación | Desplazamiento actual configurado respecto del ángulo vertical, (entre la montura y la antena) | Grados

Sistema de gráficos

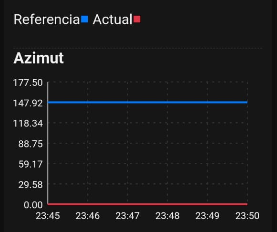
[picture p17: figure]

Estas gráficas se actualizan cada segundo y proporcionan información detallada del movimiento de la montura motorizada, se puede visualizar la referencia angular dada en cada tiempo y el ángulo actual de la plataforma.

Descripción de datos de Configuración

Satélite
Dato | Descripción | Unidad
TLE | Entrada para los elementos de dos líneas del satélite a realizar el seguimiento | -

Offsets de Antena
Dato | Descripción | Unidad
Declinación Magnética | Entrada para la declinación respecto del norte verdadero y el norte magnético. | Grados
Offset Antena | Entrada para el desplazamiento del ángulo de elevación de la antena parabólica de alimentación desplazada. | Grados
Offset Azimut | Entrada para generar un desplazamiento en azimut (útil para la instalación). | Grados
Offset Elevación | Entrada para generar un desplazamiento en elevación (útil para la instalación). | Grados

Localización y Tiempo
Dato | Descripción | Unidad
Enviar desde navegador | Botón para el envío de datos de geolocalización y tiempo desde el navegador y obtenidos desde el dispositivo. | -

Microcontrolador
Dato | Descripción | Unidad
Reiniciar | Botón para enviar una bandera de reinicio al microcontrolador ante cualquier error del sistema. | -

¿CÓMO INSTALAR LA MONTURA?

1. Se debe colocar la plataforma de la montura en una superficie correctamente nivelada.
2. Con el dispositivo encendido, conectarse a la red WiFi y acceder a la interfaz de usuario en el navegador con la URL http://tracker.local.
3. Acceder a la sección de Control Manual, en la misma enviar el comando para colocar la montura en 0° Azimut y 90° Elevación.
4. Esperar que la montura termine el proceso de calibración y se coloque adecuadamente en la posición comandada.
5. En este momento, es necesario ajustar la montura al norte geográfico o norte verdadero, para ello, se utiliza una brújula para efectuar movimientos en el eje azimut colocando el brazo de la parábola lo más cercano al norte magnético.
6. Acceder al menú de configuración para colocar la declinación magnética, el offset de elevación de la antena parabólica de alimentación desplazada y luego enviar los datos para ser almacenados. (Es posible también ajustar la montura al norte verdadero, en este caso se debe dejar la entrada de declinación magnética vacía).
7. Si por algún motivo durante la colocación, se requiere un ajuste fino en los ángulos, se puede colocar directamente en las entradas de offset Azimut y offset Elevación para evitar la manipulación de la montura.

¿CÓMO EMPIEZO A RASTREAR UN SATÉLITE?

Para seguir el movimiento de un satélite, debemos colocar en la sección de configuración la información más reciente del TLE del satélite a realizar el rastreo preprogramado, estos pueden ser obtenidos en línea en páginas como Celestrak, satellitetracker3d, SpaceTrack, N2YO, Heavens-Above,...

- Luego de enviar la información, debemos esperar a que se obtengan datos de posición y tiempo de la ubicación de la plataforma, el estado de la plataforma en la sección de Telemetría indicará la correcta configuración de los mismos cuando la información respecto del satélite sea actualizada (Punto sub-satélite, ángulos de apuntamiento,...).
- Es posible saltarse la espera mediante el envío de estos datos de ubicación y tiempo, en el apartado de configuración, Localización y Tiempo, Enviar desde Navegador. En este caso, la plataforma utilizará la información proveída por el dispositivo.

Presionando el botón de Encendido se notificará que el seguimiento se está comenzando o ante la falta de algún dato necesario; La montura comenzará moviéndose a la posición de calibración si es necesario y de inmediato comenzará el seguimiento.

En los datos de Telemetría, Montura se pueden ver gráficos del movimiento de la montura en ambos ejes y la referencia angular que se está dando actualmente para el satélite configurado.

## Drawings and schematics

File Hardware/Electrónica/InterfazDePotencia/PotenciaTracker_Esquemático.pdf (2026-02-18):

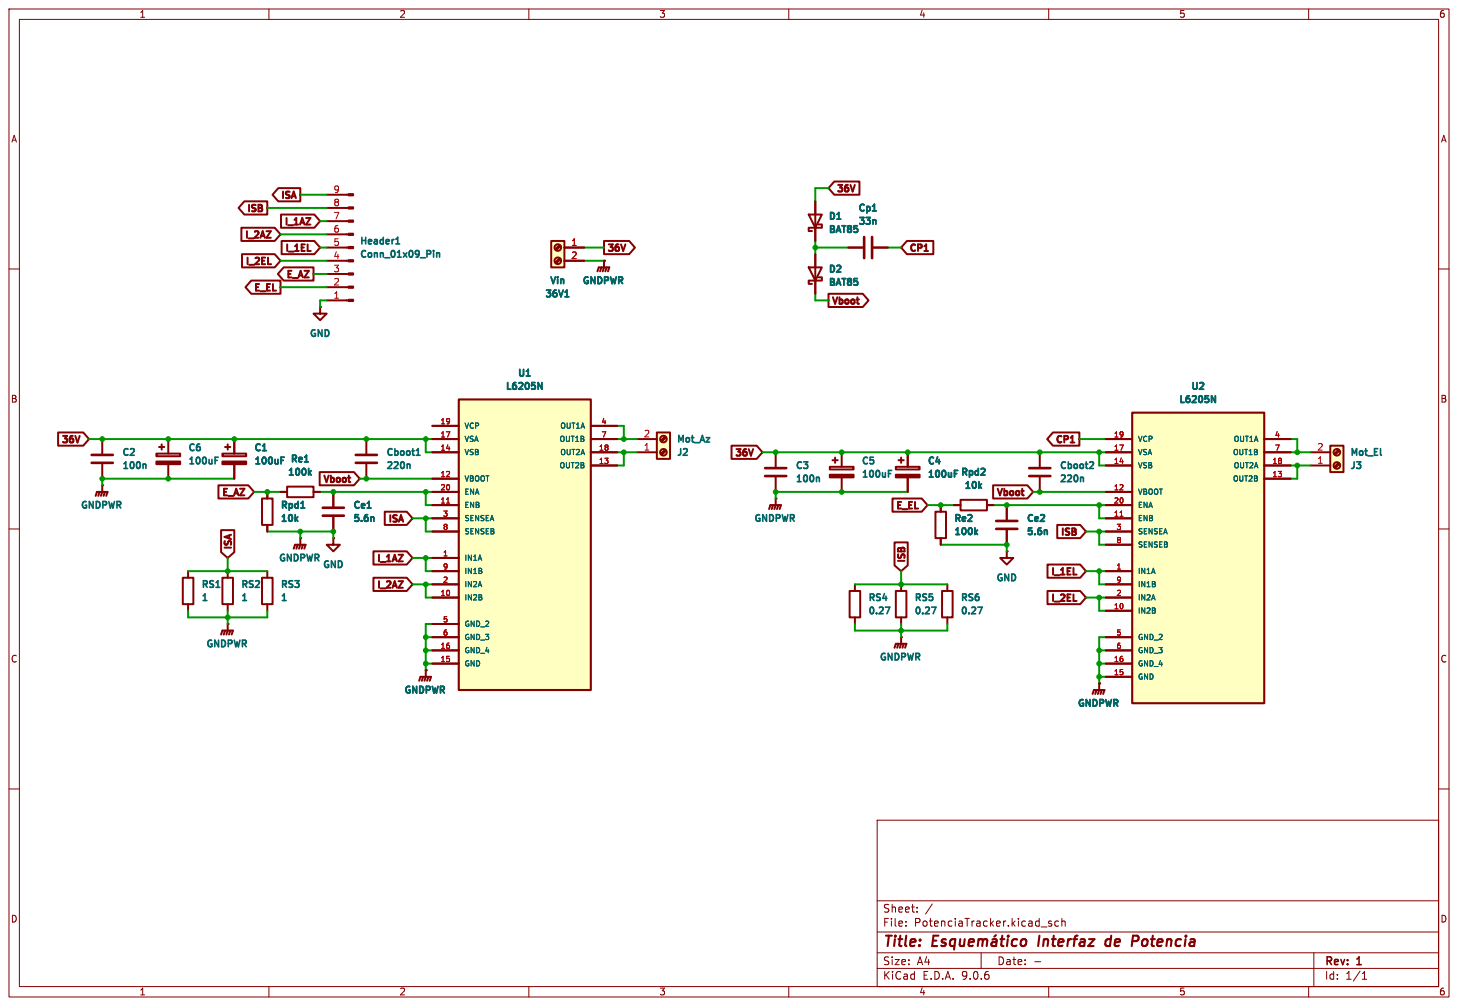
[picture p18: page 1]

File: PotenciaTracker.kicad_sch Sheet: /
Id: 1/1 Title: þÿEsquemático Interfaz de Potencia

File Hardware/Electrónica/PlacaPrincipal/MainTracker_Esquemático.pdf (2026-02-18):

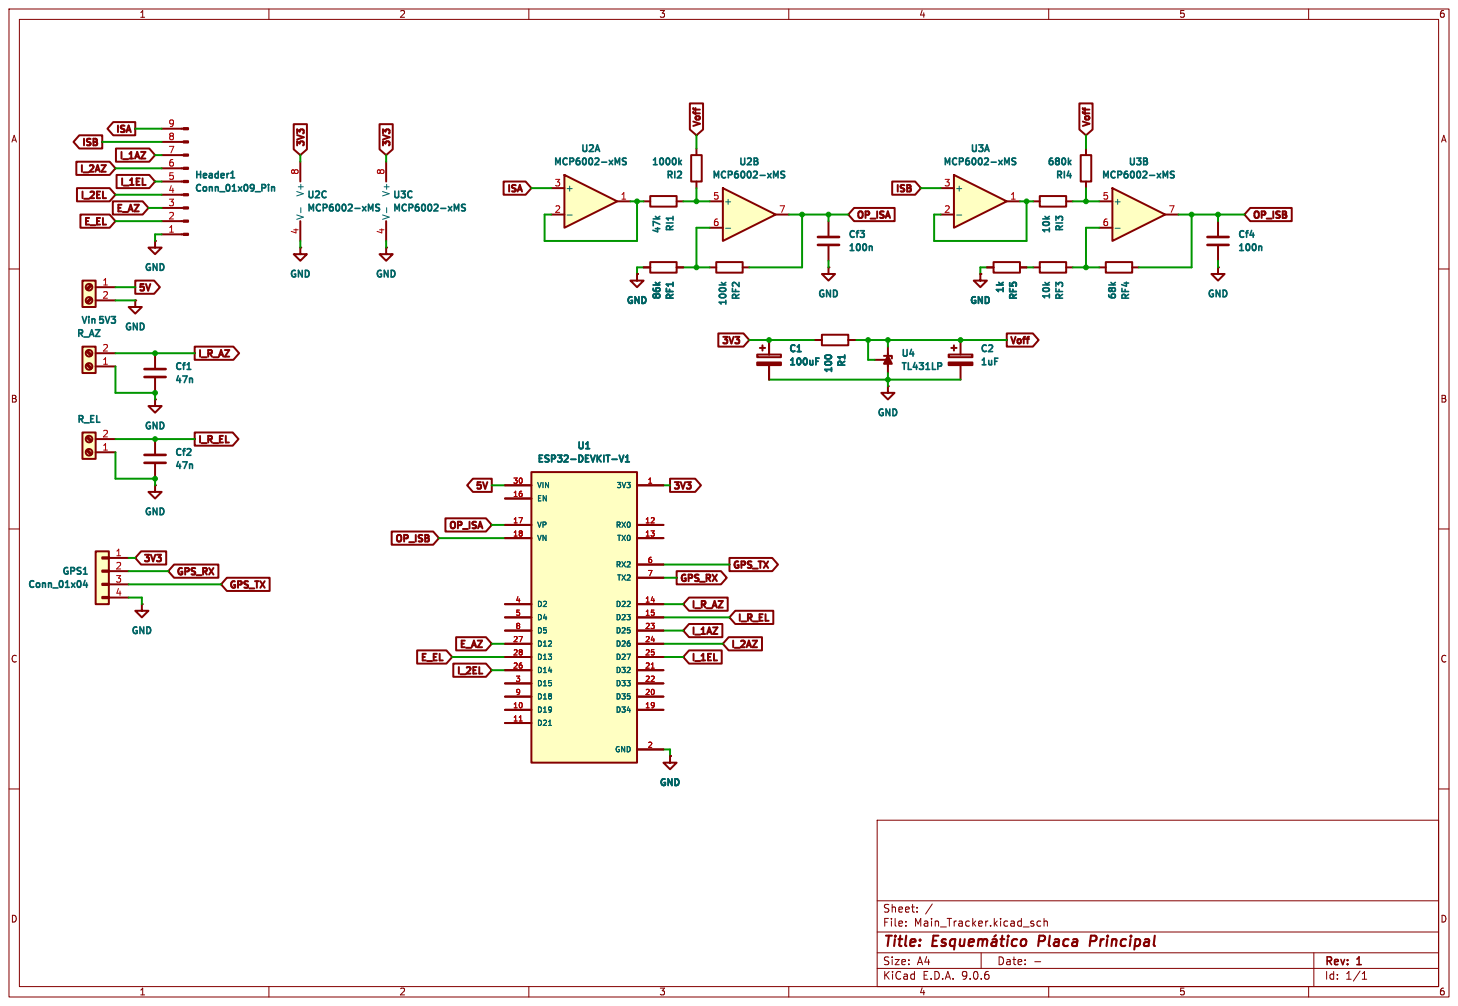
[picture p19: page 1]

Id: 1/1 Title: þÿEsquemático Placa Principal File: Main_Tracker.kicad_sch Sheet: /

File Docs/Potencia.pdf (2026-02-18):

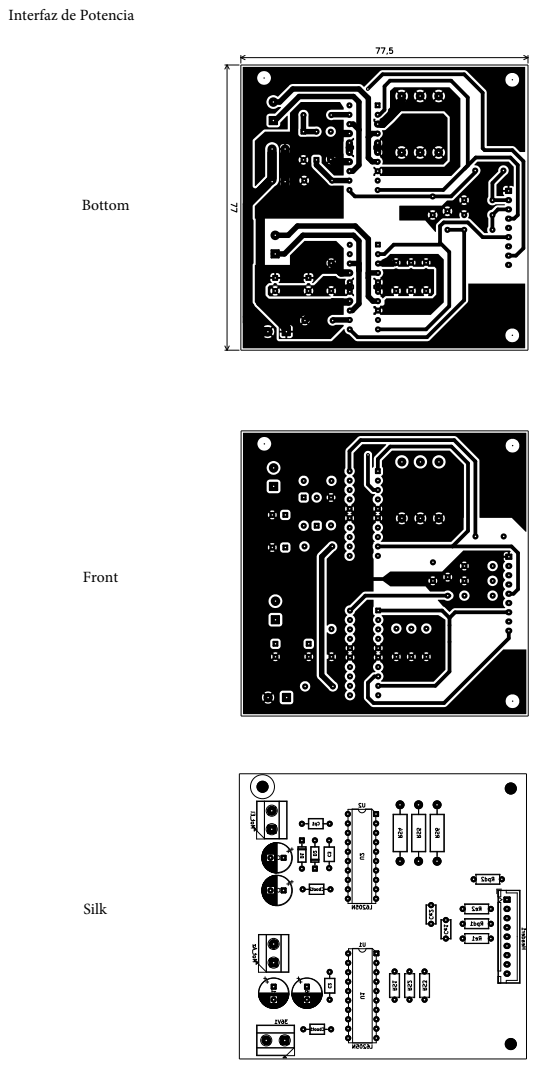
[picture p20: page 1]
Bottom; Front; Silk

Interfaz de Potencia

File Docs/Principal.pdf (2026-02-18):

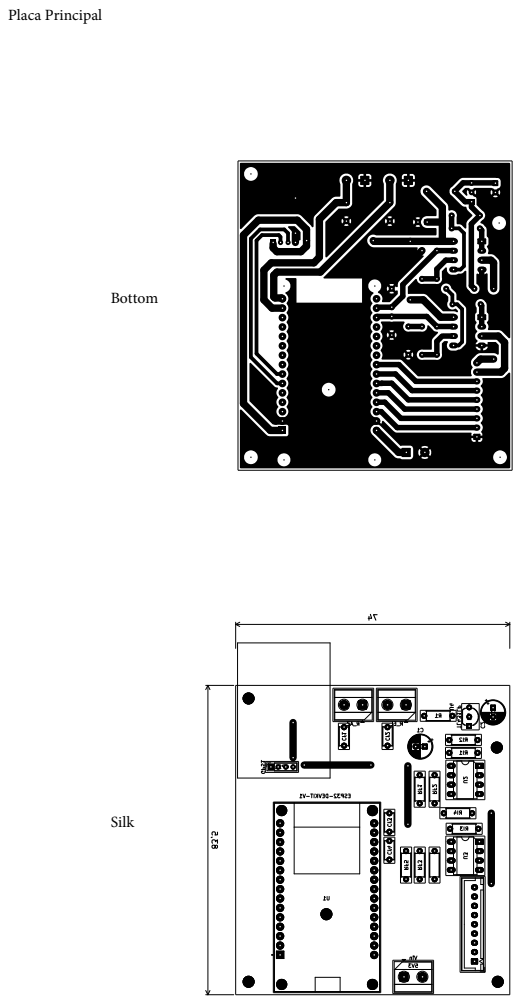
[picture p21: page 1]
Bottom; Silk; Placa Principal

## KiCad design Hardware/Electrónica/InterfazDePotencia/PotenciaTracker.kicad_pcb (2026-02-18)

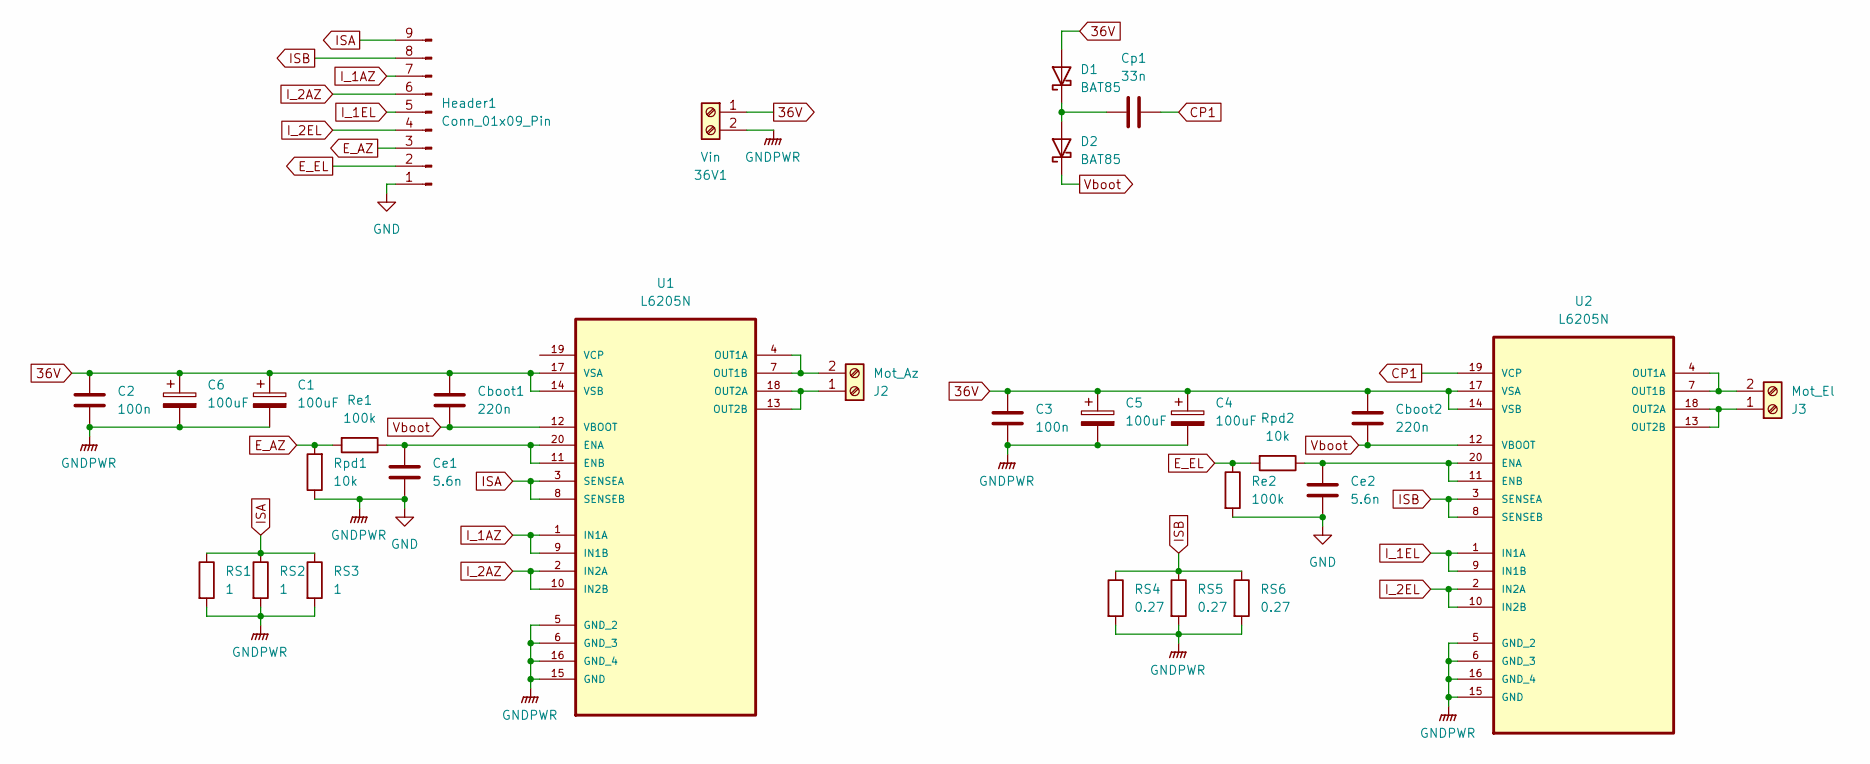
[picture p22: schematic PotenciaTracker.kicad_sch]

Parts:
36V1: Vin; TerminalBlock_MetzConnect_Type055_RT01502HDWU_1x02_P5.00mm_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
C1, C4, C5, C6: 100uF; CP_Radial_D8.0mm_P3.50mm
C2, C3: 100n; C_Axial_L3.8mm_D2.6mm_P7.50mm_Horizontal
Cboot1, Cboot2: 220n; C_Axial_L3.8mm_D2.6mm_P7.50mm_Horizontal
Ce1, Ce2: 5.6n; C_Disc_D5.0mm_W2.5mm_P5.00mm
Cp1: 33n; C_Axial_L3.8mm_D2.6mm_P7.50mm_Horizontal
D1, D2: BAT85; D_DO-35_SOD27_P7.62mm_Horizontal
Header1: Conn_01x09_Pin; JST_XH_B9B-XH-A_1x09_P2.50mm_Vertical
J2: Mot_Az; TerminalBlock_MetzConnect_Type055_RT01502HDWU_1x02_P5.00mm_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
J3: Mot_El; TerminalBlock_MetzConnect_Type055_RT01502HDWU_1x02_P5.00mm_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
RS1, RS2, RS3: 1; R_Axial_DIN0207_L6.3mm_D2.5mm_P7.62mm_Horizontal
RS4, RS5, RS6: 0.27; R_Axial_DIN0411_L9.9mm_D3.6mm_P15.24mm_Horizontal
Re1, Re2: 100k; R_Axial_DIN0207_L6.3mm_D2.5mm_P7.62mm_Horizontal
Rpd1, Rpd2: 10k; R_Axial_DIN0207_L6.3mm_D2.5mm_P7.62mm_Horizontal
U1, U2: L6205N; CERDIP-20_W7.62mm_SideBrazed; MPN L6205N

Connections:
36V: 36V1.1, C1.1, C2.1, C3.1, C4.1, C5.1, C6.1, Cboot1.1, Cboot2.1, D1.2 (A), U1.14 (VSB), U1.17 (VSA), U2.14 (VSB), U2.17 (VSA)
CP1: Cp1.1, U2.19 (VCP)
E_AZ: Header1.3, Re1.2, Rpd1.2
E_EL: Header1.2, Re2.1, Rpd2.2
GND: 36V1.2, C1.2, C2.2, C3.2, C4.2, C5.2, C6.2, Ce1.2, Ce2.2, Header1.1, RS1.2, RS2.2, RS3.2, RS4.2, RS5.2, RS6.2, Re2.2, Rpd1.1, U1.5 (GND_2), U1.6 (GND_3), U1.15 (GND), U1.16 (GND_4), U2.5 (GND_2), U2.6 (GND_3), U2.15 (GND), U2.16 (GND_4)
ISA: Header1.9, RS1.1, RS2.1, RS3.1, U1.3 (SENSEA), U1.8 (SENSEB)
ISB: Header1.8, RS4.1, RS5.1, RS6.1, U2.3 (SENSEA), U2.8 (SENSEB)
I_1AZ: Header1.7, U1.1 (IN1A), U1.9 (IN1B)
I_1EL: Header1.5, U2.1 (IN1A), U2.9 (IN1B)
I_2AZ: Header1.6, U1.2 (IN2A), U1.10 (IN2B)
I_2EL: Header1.4, U2.2 (IN2A), U2.10 (IN2B)
unnamed: Cp1.2, D1.1 (K), D2.2 (A)
unnamed: J2.1, U1.13 (OUT2B), U1.18 (OUT2A)
unnamed: J2.2, U1.4 (OUT1A), U1.7 (OUT1B)
unnamed: J3.1, U2.13 (OUT2B), U2.18 (OUT2A)
unnamed: J3.2, U2.4 (OUT1A), U2.7 (OUT1B)
unnamed: Ce1.1, Re1.1, U1.11 (ENB), U1.20 (ENA)
unnamed: Ce2.1, Rpd2.1, U2.11 (ENB), U2.20 (ENA)
Vboot: Cboot1.2, Cboot2.2, D2.1 (K), U1.12 (VBOOT), U2.12 (VBOOT)

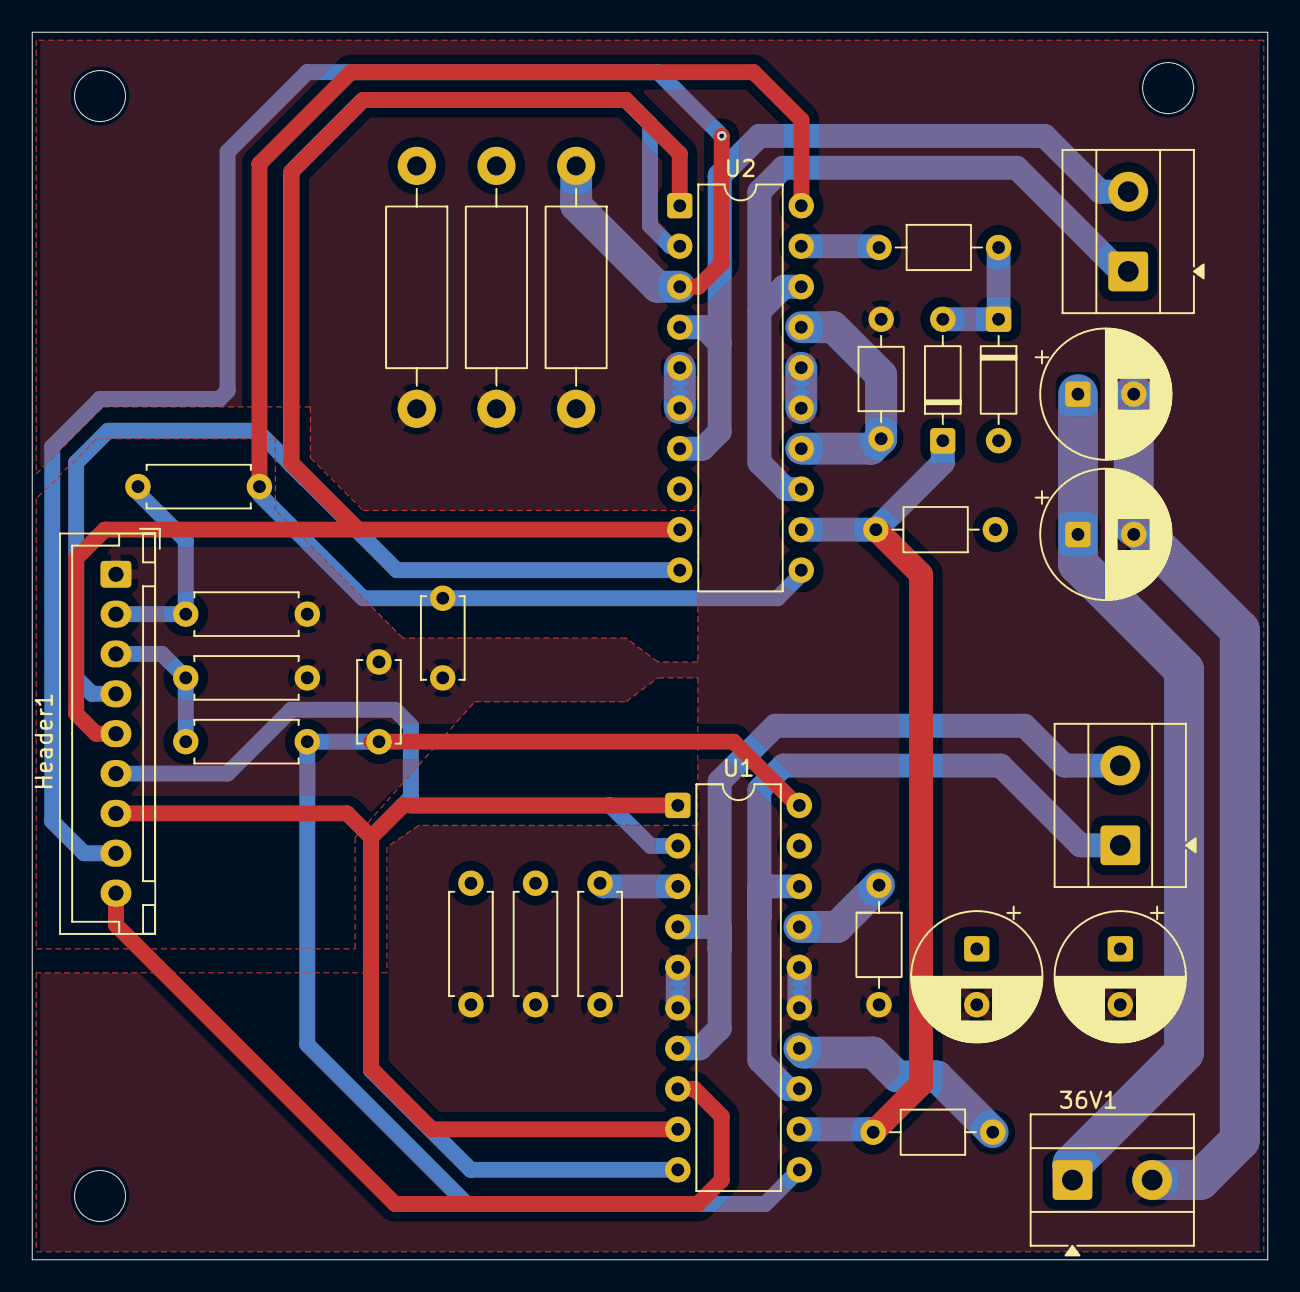
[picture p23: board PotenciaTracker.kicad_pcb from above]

Board: 2 copper layers, 77.5 x 77.0 mm, 29 parts (0 on the bottom side), 19 nets.

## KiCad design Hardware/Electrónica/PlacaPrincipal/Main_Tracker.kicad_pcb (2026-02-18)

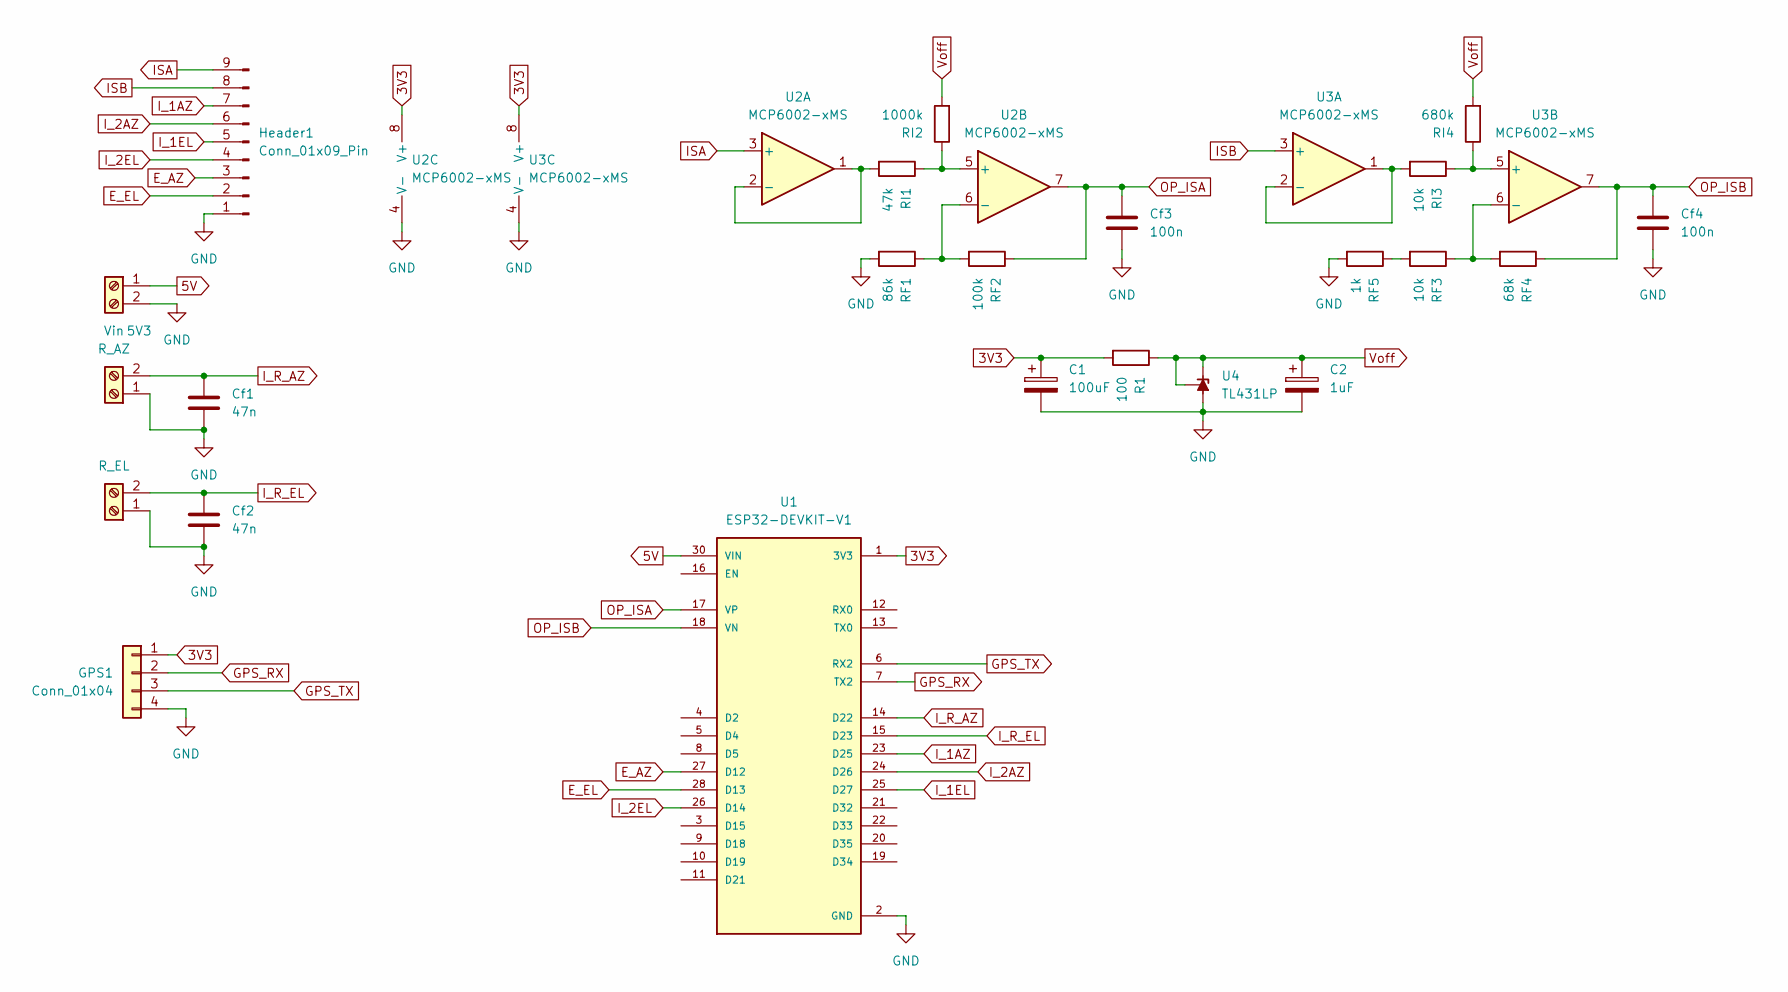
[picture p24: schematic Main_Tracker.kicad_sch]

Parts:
5V1: R_AZ; TerminalBlock_MetzConnect_Type055_RT01502HDWU_1x02_P5.00mm_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
5V2: R_EL; TerminalBlock_MetzConnect_Type055_RT01502HDWU_1x02_P5.00mm_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
5V3: Vin; TerminalBlock_MetzConnect_Type055_RT01502HDWU_1x02_P5.00mm_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
C1: 100uF; CP_Radial_D6.3mm_P2.50mm
C2: 1uF; CP_Radial_D6.3mm_P2.50mm
Cf1, Cf2: 47n; C_Disc_D5.0mm_W2.5mm_P5.00mm
Cf3, Cf4: 100n; C_Disc_D5.0mm_W2.5mm_P5.00mm
GPS1: Conn_01x04; PinHeader_1x04_P2.00mm_Vertical
Header1: Conn_01x09_Pin; JST_XH_B9B-XH-A_1x09_P2.50mm_Vertical
R1: 100; R_Axial_DIN0207_L6.3mm_D2.5mm_P7.62mm_Horizontal
RF1: 86k; R_Axial_DIN0207_L6.3mm_D2.5mm_P7.62mm_Horizontal
RF2: 100k; R_Axial_DIN0207_L6.3mm_D2.5mm_P7.62mm_Horizontal
RF3: 10k; R_Axial_DIN0207_L6.3mm_D2.5mm_P7.62mm_Horizontal
RF4: 68k; R_Axial_DIN0207_L6.3mm_D2.5mm_P7.62mm_Horizontal
RF5: 1k; R_Axial_DIN0207_L6.3mm_D2.5mm_P7.62mm_Horizontal
RI1: 47k; R_Axial_DIN0207_L6.3mm_D2.5mm_P7.62mm_Horizontal
RI2: 1000k; R_Axial_DIN0207_L6.3mm_D2.5mm_P7.62mm_Horizontal
RI3: 10k; R_Axial_DIN0207_L6.3mm_D2.5mm_P7.62mm_Horizontal
RI4: 680k; R_Axial_DIN0207_L6.3mm_D2.5mm_P7.62mm_Horizontal
U1: ESP32-DEVKIT-V1; MODULE_ESP32_DEVKIT_V1; PARTREV N/A
U2, U3: MCP6002-xMS; DIP-8_W7.62mm_LongPads
U4: TL431LP; TO-92_Inline_Wide

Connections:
3V3: C1.1, GPS1.1, R1.2, U1.1 (3V3), U2.8 (V+), U3.8 (V+)
5V: 5V3.1, U1.30 (VIN)
E_AZ: Header1.3, U1.27 (D12)
E_EL: Header1.2, U1.28 (D13)
GND: 5V1.1, 5V2.1, 5V3.2, C1.2, C2.2, Cf1.2, Cf2.2, Cf3.2, Cf4.2, GPS1.4, Header1.1, RF1.2, RF5.2, U1.2 (GND), U1.29 (GND), U2.4 (V-), U3.4 (V-), U4.2 (A)
GPS_RX: GPS1.2, U1.7 (TX2)
GPS_TX: GPS1.3, U1.6 (RX2)
ISA: Header1.9, U2.3 (+)
ISB: Header1.8, U3.3 (+)
I_1AZ: Header1.7, U1.23 (D25)
I_1EL: Header1.5, U1.25 (D27)
I_2AZ: Header1.6, U1.24 (D26)
I_2EL: Header1.4, U1.26 (D14)
I_R_AZ: 5V1.2, Cf1.1, U1.14 (D22)
I_R_EL: 5V2.2, Cf2.1, U1.15 (D23)
unnamed: RF3.2, RF5.1
unnamed: RI1.2, U2.1, U2.2 (-)
unnamed: RI1.1, RI2.1, U2.5 (+)
unnamed: RF1.1, RF2.2, U2.6 (-)
unnamed: RI3.2, U3.1, U3.2 (-)
unnamed: RI3.1, RI4.1, U3.5 (+)
unnamed: RF3.1, RF4.2, U3.6 (-)
OP_ISA: Cf3.1, RF2.1, U1.17 (VP), U2.7
OP_ISB: Cf4.1, RF4.1, U1.18 (VN), U3.7
Voff: C2.1, R1.1, RI2.2, RI4.2, U4.1 (REF), U4.3 (K)

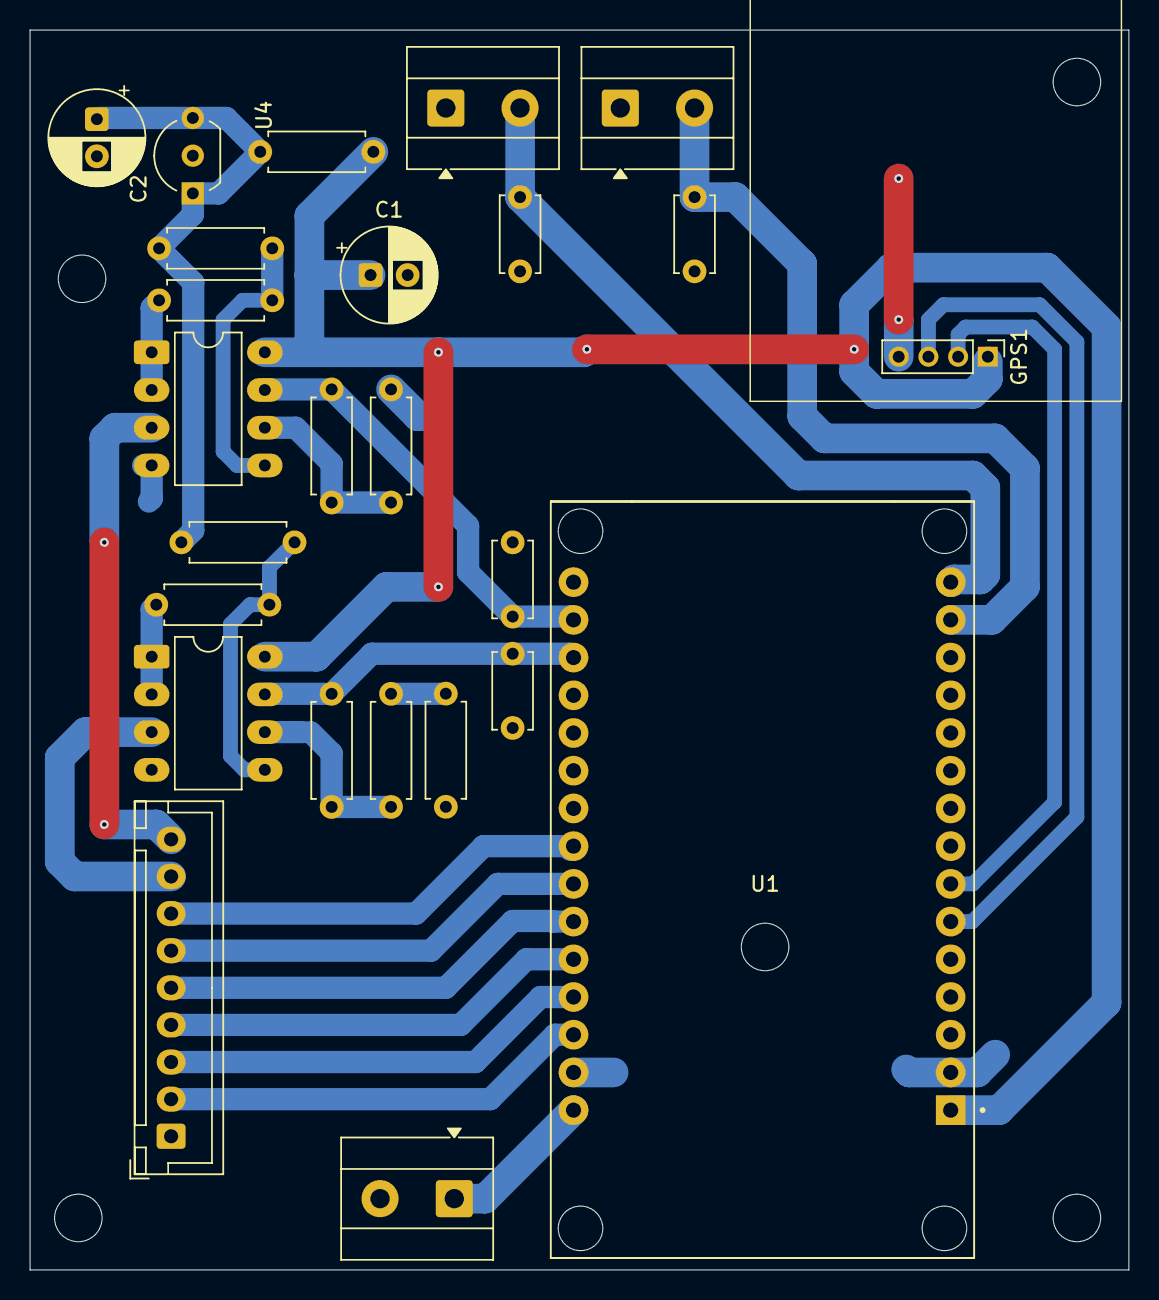
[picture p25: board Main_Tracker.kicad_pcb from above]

Board: 2 copper layers, 74.0 x 83.5 mm, 25 parts (0 on the bottom side), 25 nets.

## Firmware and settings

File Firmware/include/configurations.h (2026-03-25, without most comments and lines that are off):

#pragma once
#include <Arduino.h>
#include "driver/gpio.h"
#define IN1_AZ_PIN GPIO_NUM_25
#define EN_AZ_PIN GPIO_NUM_12
#define IN2_AZ_PIN GPIO_NUM_26
#define I_AZ_PIN GPIO_NUM_36
#define I_AZ_CHANNEL ADC1_CHANNEL_0
#define IN1_EL_PIN GPIO_NUM_27
#define EN_EL_PIN GPIO_NUM_13
#define IN2_EL_PIN GPIO_NUM_14
#define I_EL_PIN GPIO_NUM_39
#define I_EL_CHANNEL ADC1_CHANNEL_3
#define GPS_RX_PIN 16
#define GPS_TX_PIN 17
#define REED_AZ_PIN GPIO_NUM_22
#define REED_EL_PIN GPIO_NUM_23
#define A_ANT 50.0f
#define BP_ANT 220.11f
#define C_ANT 276.00f
#define D_ANT 145.0f
#define E_ANT 80.0f
#define F_ANT 258.00f
#define DEFAULT_WIFI_SSID "TrackerLARFyM"
#define DEFAULT_WIFI_PASSWORD ""
#define DEFAULT_SERVER_PORT 80
#define MDNS_SERVICE_NAME "Tracker"
#define SERIAL_BAUDRATE 115200
#define GPS_UART 1
#define GPS_BAUDRATE 9600
#define M_V_NOMINAL 36
#define M_AZ_V_TO_START 15.5
#define M_EL_V_TO_START 9
#define M_STOP_DUTY 25
#define M_MAX_DUTY 100
#define M_AZ_SETTLING_TIME_MS 65
#define M_EL_SETTLING_TIME_MS 100
#define M_STOPPED_CHECK_INTERVAL_MS 10
#define AZIMUTH_RESOLUTION_angle 0.225
#define ELEVATION_RESOLUTION_mm 0.8
#define CURRENT_AZIMUTH_MAX_mA 1000.0
#define CURRENT_ELEVATION_MAX_mA 1000.0
#define CURRENT_HOMING_mA 10.0
#define TIMER_PREESCALER 80
#define DEFAULT_SAMPLE_TIME_US 500
#define SAMPLE_TIME_US 500
#define SAMPLE_TIME_S (SAMPLE_TIME_US / 1000000.0)
#define SAMPLE_TIME_SGP4_MS 50
#define KP_AZIMUTH 10.0
#define KI_AZIMUTH 1
#define KP_ELEVATION 7.0
#define KI_ELEVATION 0.5
#define REED_AZ_SOFT_LIMIT_HIGH 1610
#define REED_EL_SOFT_LIMIT_HIGH 435
#define REED_AZ_SOFT_LIMIT_LOW -5
#define REED_EL_SOFT_LIMIT_LOW -5
#define EL_MIN_DEG 0
#define EL_MAX_DEG 90
#define AZ_MIN_DEG 0
#define AZ_MAX_DEG 340
#define PWM_FREQ_HZ 2500 // Note: It increases power dissipation in MOSFETS
#define SHUNT_AZ_OHM 0.3333333
#define CURRENT_GAIN_AZ 2.11988
#define SHUNT_EL_OHM 0.09
#define CURRENT_GAIN_EL 7.07773
#define ADC_MEASURE_SAMPLES 128
#define TASK_STOP_MOTION_PRIORITY 17
#define TASK_HOME_PRIORITY 16
#define TASK_GPS_PRIORITY 15
#define TASK_TRACKING_CALCULATION_PRIORITY 14
#define TASK_MOTION_CONTROL_PRIORITY 14
#define TASK_CURRENT_MONITOR_PRIORITY 12
#define TASK_TELEMETRY_PRIORITY 11
#define TASK_LOOP_DELAY 1000
#define TASK_GPS_DELAY 1000
#define TASK_CURRENT_MONITOR_DELAY 3000
#define TASK_HOME_CURRENT_DELAY 200
#define TASK_TELEMETRY_DELAY 1000
#define MAX_STACK_SIZE 8192
#define MEDIUM_STACK_SIZE 2048
#define MIN_STACK_SIZE 1024

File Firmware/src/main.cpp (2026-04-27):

#include "utils.h"
#include "PI_Controller.h"
#include "server.h"
#include "currentSensor.h"
#include "reed.h"
#include "motorDriver.h"
#include "configurations.h"

/* Library Objects */
Sgp4 satellite;
Preferences config;
HardwareSerial gpsSerial(GPS_UART);
TinyGPSPlus gps;
ServerHandler serverHandler(DEFAULT_SERVER_PORT);

/* Discrete Controllers */
PI_Controller controllerAz(KP_AZIMUTH, KI_AZIMUTH, SAMPLE_TIME_S, M_AZ_V_TO_START, M_V_NOMINAL);
PI_Controller controllerEl(KP_ELEVATION, KI_ELEVATION, SAMPLE_TIME_S, M_EL_V_TO_START, M_V_NOMINAL);

/* Reed Switch Handlers */
void IRAM_ATTR reedAz_event_handler(void *arg);
void IRAM_ATTR reedEl_event_handler(void *arg);

/* ISRs */
void controlTimer_ISR(void *arg);

/* Components */
ReedSwitch reedAz(REED_AZ_PIN, PCNT_UNIT_0, PCNT_CHANNEL_0, REED_AZ_SOFT_LIMIT_LOW, REED_AZ_SOFT_LIMIT_HIGH, reedAz_event_handler);
ReedSwitch reedEl(REED_EL_PIN, PCNT_UNIT_1, PCNT_CHANNEL_0, REED_EL_SOFT_LIMIT_LOW, REED_EL_SOFT_LIMIT_HIGH, reedEl_event_handler);
MotorDriver motorAz(IN1_AZ_PIN, IN2_AZ_PIN, EN_AZ_PIN, LEDC_TIMER_0, LEDC_CHANNEL_0, PWM_FREQ_HZ);
MotorDriver motorEl(IN1_EL_PIN, IN2_EL_PIN, EN_EL_PIN, LEDC_TIMER_0, LEDC_CHANNEL_1, PWM_FREQ_HZ);
CurrentSensor currentAz(I_AZ_CHANNEL);
CurrentSensor currentEl(I_EL_CHANNEL);

/* Task Handlers */
TaskHandle_t GPS_TaskHandle = NULL;
TaskHandle_t TrackingPredictor_TaskHandle = NULL;
TaskHandle_t MotionControl_TaskHandle = NULL;
TaskHandle_t StopMotion_TaskHandle = NULL;
TaskHandle_t Calibration_TaskHandle = NULL;

/* freeRTOS Tasks */
void GPS_Task(void *pvParameters);
void TrackingPredictor_Task(void *pvParameters);
void MotionControl_Task(void *pvParameters);
void StopMotion_Task(void *pvParameters);
void Calibration_Task(void *pvParameters);
void CurrentMonitor_Task(void *pvParameters);
void telemetry_Task(void *pvParameters);

/* Global Variables */
static const char *TAG = "MAIN";
sphericalAngles_t targetAngle = {0};
sphericalAngles_t sgp4TargetAngle = {0};
sphericalAngles_t manualTargetAngle = {0};
sphericalAngles_t setPointAngle = {0};
sphericalAngles_t mountAngle = {0};
sphericalAngles_t offsetAngle = {0};
mountFlags_t flags;
trackerStatus_t status;
unsigned long nextPass_unix = 0;

void setup()
{
  esp_log_level_set("*", ESP_LOG_VERBOSE);
  Serial.begin(SERIAL_BAUDRATE);

  init_elevation_lut();

  /* Init Calibrations & Configs*/
  currentAz.setShuntValue(SHUNT_AZ_OHM);
  currentEl.setShuntValue(SHUNT_EL_OHM);
  currentAz.setOpAmpGain(CURRENT_GAIN_AZ);
  currentEl.setOpAmpGain(CURRENT_GAIN_EL);
  currentAz.calibrateOffset();
  currentEl.calibrateOffset();
  ESP_LOGI(TAG, "Shunt-Voltage-Offsets: Az %d [mV], El %d [mV]", currentAz.getOffset_mV(), currentEl.getOffset_mV());
  offsetAngle = getSavedOffsets();
  ESP_LOGI(TAG, "Antenna-Offsets: Az %.3f [°], El %.3f [°]", offsetAngle.azimuth, offsetAngle.elevation);

  controllerAz.setDeadZone(M_AZ_V_TO_START);
  controllerEl.setDeadZone(M_EL_V_TO_START);

  gpsSerial.begin(GPS_BAUDRATE, SERIAL_8N1, GPS_RX_PIN, GPS_TX_PIN);
  status.tle = configSatellite(&satellite);
  configControlTimer(controlTimer_ISR, SAMPLE_TIME_US);

  // Starting Tasks
  xTaskCreate(StopMotion_Task, "Stop Motion Task", MEDIUM_STACK_SIZE, NULL, TASK_STOP_MOTION_PRIORITY, &StopMotion_TaskHandle);
  xTaskCreate(telemetry_Task, "Telemetry Task", MAX_STACK_SIZE, NULL, TASK_TELEMETRY_PRIORITY, NULL);
  // xTaskCreate(CurrentMonitor_Task, "Current Monitor Task", MEDIUM_STACK_SIZE, NULL, 12, NULL);

  serverHandler.start();
}

void loop()
{
  // Reset
  if (flags.reset_pending == true)
  {
    ESP_LOGI(TAG, "Restarting...");
    vTaskDelay(pdMS_TO_TICKS(2000));
    ESP.restart();
  }

  // Update TLE if changed
  if (flags.tle_updated == true)
  {
    status.tle = (configSatellite(&satellite) ? true : false);
    flags.tle_updated = false;
    flags.pred_done = false;
    nextPass_unix = 0;
  }

  // Update Offsets if changed
  if (flags.offsets_updated == true)
  {
    offsetAngle = getSavedOffsets();
    flags.offsets_updated = false;
    flags.pred_done = false;
    nextPass_unix = 0;
  }

  // GPS Task When no data
  if (status.gps == false && GPS_TaskHandle == NULL)
  {
    ESP_LOGI(TAG, "Starting GPS Task");
    xTaskCreate(GPS_Task, "GPS Task", MEDIUM_STACK_SIZE, NULL, TASK_GPS_PRIORITY, &GPS_TaskHandle);
  }

  // SGP4 Calculation Task When possible
  if (status.tle == true && status.gps == true && TrackingPredictor_TaskHandle == NULL)
  {
    ESP_LOGI(TAG, "Starting Predictor Task");
    xTaskCreate(TrackingPredictor_Task, "Predictor Task", MAX_STACK_SIZE, NULL, TASK_TRACKING_CALCULATION_PRIORITY, &TrackingPredictor_TaskHandle);
  }

  // Tracking Management
  if (status.tracking == true)
  {
    flags.stop_done = false;
    // Calibration Task
    if (!flags.home_done && Calibration_TaskHandle == NULL)
    {
      ESP_LOGI(TAG, "Starting Calibration Task");
      xTaskCreate(Calibration_Task, "Calibration", MEDIUM_STACK_SIZE, NULL, TASK_HOME_PRIORITY, &Calibration_TaskHandle);
    }
    else if (flags.home_done && MotionControl_TaskHandle == NULL)
    {
      ESP_LOGI(TAG, "Starting Motion Control Task");
      xTaskCreate(MotionControl_Task, "Motion Control", MAX_STACK_SIZE, NULL, TASK_MOTION_CONTROL_PRIORITY, &MotionControl_TaskHandle);
    }
  }
  // Stopping
  else
  {
    if (!flags.stop_done && StopMotion_TaskHandle == NULL)
    {
      ESP_LOGI(TAG, "Starting Stop Motion Task");
      xTaskCreate(StopMotion_Task, "Stop Motion", MEDIUM_STACK_SIZE, NULL, TASK_STOP_MOTION_PRIORITY, &StopMotion_TaskHandle);
    }
  }

  vTaskDelay(pdMS_TO_TICKS(TASK_LOOP_DELAY));
}

// SampleTime ISR for Motion Control Task
void IRAM_ATTR controlTimer_ISR(void *arg)
{
  timer_group_clr_intr_status_in_isr(TIMER_GROUP_0, TIMER_1);
  timer_group_enable_alarm_in_isr(TIMER_GROUP_0, TIMER_1);

  BaseType_t xHigherPriorityTaskWoken = pdFALSE;
  if (status.tracking == true && MotionControl_TaskHandle != NULL)
  {
    vTaskNotifyGiveFromISR(MotionControl_TaskHandle, &xHigherPriorityTaskWoken);
  }
  portYIELD_FROM_ISR(xHigherPriorityTaskWoken);
}

// PI & Movement
void MotionControl_Task(void *pvParameters)
{
  constexpr float DUTY_SCALE = 100.0f / M_V_NOMINAL;

  float el_mm = 0.0f;
  float output_az = 0.0, output_el = 0.0;
  int new_dir_az = 0, new_dir_el = 0, current_dir_az = 0, current_dir_el = 0;

  for (;;)
  {
    ulTaskNotifyTake(pdTRUE, portMAX_DELAY);

    if (StopMotion_TaskHandle == NULL)
    {
      // SetPoint
      if (status.manual_tracking == true)
      {
        setPointAngle.azimuth = manualTargetAngle.azimuth;
        setPointAngle.elevation = manualTargetAngle.elevation;
      }
      else
      {
        setPointAngle.azimuth = (targetAngle.azimuth < 0.0f) ? targetAngle.azimuth + 360.0f : targetAngle.azimuth;
        setPointAngle.elevation = targetAngle.elevation;
      }

      setPointAngle.azimuth = fmaxf(fminf(setPointAngle.azimuth, AZ_MAX_DEG), AZ_MIN_DEG);
      setPointAngle.elevation = fmaxf(fminf(setPointAngle.elevation, EL_MAX_DEG), EL_MIN_DEG);

      el_mm = reedEl.getCount() * ELEVATION_RESOLUTION_mm;
      mountAngle.elevation = elevation_deg_from_mm(el_mm);
      mountAngle.azimuth = reedAz.getCount() * AZIMUTH_RESOLUTION_angle;

      // PID Controller
      output_az = controllerAz.output(mountAngle.azimuth, setPointAngle.azimuth);
      output_el = controllerEl.output(el_mm, elevation_mm_from_deg(setPointAngle.elevation));

      // CONTROL ACTION
      new_dir_az = (output_az > 0) ? FORWARD : (output_az < 0) ? BACKWARD
                                                               : current_dir_az;
      new_dir_el = (output_el > 0) ? FORWARD : (output_el < 0) ? BACKWARD
                                                               : current_dir_el;

      // Azimut
      if (new_dir_az != current_dir_az)
      {
        // Command stop & Check actual stopping
        motorAz.stop();
        vTaskDelay(pdMS_TO_TICKS(M_AZ_SETTLING_TIME_MS));
        while (currentAz.getCurrent_mA() > CURRENT_HOMING_mA)
        {
          vTaskDelay(pdMS_TO_TICKS(M_STOPPED_CHECK_INTERVAL_MS));
        }

        controllerAz.reset();
        motorAz.setDuty(0);
        reedAz.countDirection((direction)new_dir_az);
        motorAz.setDirection((direction)new_dir_az);
        current_dir_az = new_dir_az;
      }

      // Elevation
      if (new_dir_el != current_dir_el)
      {
        // Command stop & Check actual stopping
        motorEl.stop();
        vTaskDelay(pdMS_TO_TICKS(M_EL_SETTLING_TIME_MS));
        while (currentEl.getCurrent_mA() > CURRENT_HOMING_mA)
        {
          vTaskDelay(pdMS_TO_TICKS(M_STOPPED_CHECK_INTERVAL_MS));
        }

        controllerEl.reset();
        motorEl.setDuty(0);
        reedEl.countDirection((direction)new_dir_el);
        motorEl.setDirection((direction)new_dir_el);
        current_dir_el = new_dir_el;
      }

      motorAz.setDuty(fabsf(output_az) * DUTY_SCALE);
      motorEl.setDuty(fabsf(output_el) * DUTY_SCALE);
    }
  }
}

// Calculate SGP4 & Interpolations
void TrackingPredictor_Task(void *pvParameters)
{
  TickType_t time_ms_ref = 0;
  unsigned long last_unixTime = 0;
  double az[2], el[2];
  bool first_run = true;
  const uint8_t search_iterations = 30;

  for (;;)
  {

    if (!status.manual_tracking)
    {
      unsigned long current_time_ms = millis();
      unsigned long current_unixTime = time(NULL);

      if (current_unixTime == last_unixTime)
      {
        // Lineal Interpolation
        double delta_s = (current_time_ms - time_ms_ref) / 1000.0;
        if (delta_s >= 1.0)
        {
          sgp4TargetAngle.azimuth = az[1];
          sgp4TargetAngle.elevation = el[1];
        }
        else
        {
          sgp4TargetAngle.azimuth = az[0] + (az[1] - az[0]) * delta_s;
          sgp4TargetAngle.elevation = el[0] + (el[1] - el[0]) * delta_s;
        }
      }
      else
      {
        if (first_run == true)
        {
          first_run = false;
          satellite.findsat(current_unixTime);
          az[0] = satellite.satAz;
          el[0] = satellite.satEl;

          satellite.findsat(current_unixTime + 1);
          az[1] = satellite.satAz;
          el[1] = satellite.satEl;
        }
        else
        {
          az[0] = az[1];
          el[0] = el[1];

          satellite.findsat(current_unixTime + 1);
          az[1] = satellite.satAz;
          el[1] = satellite.satEl;
        }

        last_unixTime = current_unixTime;
        time_ms_ref = current_time_ms;

        sgp4TargetAngle.azimuth = az[0];
        sgp4TargetAngle.elevation = el[0];
      }
    }

    // Below Horizon - Next Pass Prediction
    if (sgp4TargetAngle.elevation < offsetAngle.elevation)
    {
      if (!flags.pred_done)
      {
        passinfo nextPass_info;
        satellite.initpredpoint((unsigned long)time(NULL), offsetAngle.elevation);
        if (satellite.nextpass(&nextPass_info, search_iterations, false, offsetAngle.elevation))
        {
          nextPass_unix = jdToUnix(nextPass_info.jdstart);
          targetAngle.azimuth = nextPass_info.azstart - offsetAngle.azimuth;
          targetAngle.elevation = EL_MIN_DEG;
          ESP_LOGI(TAG, "NextPass - Az: %.2f [°], El: %.2f [°]", nextPass_info.azstart, EL_MIN_DEG);
        }
        else
        {
          nextPass_unix = 0;
          ESP_LOGI(TAG, "No upcoming pass found above the horizon.");
          targetAngle.azimuth = AZ_MIN_DEG;
          targetAngle.elevation = EL_MAX_DEG;
        }
        flags.pred_done = true;
      }
    }
    else
    {
      nextPass_unix = 0;
      flags.pred_done = false;
      targetAngle.azimuth = sgp4TargetAngle.azimuth - offsetAngle.azimuth;
      targetAngle.elevation = sgp4TargetAngle.elevation - offsetAngle.elevation;
    }

    vTaskDelay(pdMS_TO_TICKS(SAMPLE_TIME_SGP4_MS));
  }
}

void GPS_Task(void *pvParameters)
{
  bool time_set = false;
  for (;;)
  {
    if (status.gps == true)
    {
      vTaskDelete(NULL);
    }

    while (gpsSerial.available() > 0)
    {
      gps.encode(gpsSerial.read());
    }

    if (gps.time.isUpdated() && gps.date.isUpdated() && gps.time.isValid() && gps.date.isValid() && !time_set)
    {
      struct tm t;
      t.tm_year = gps.date.year() - 1900;
      t.tm_mon = gps.date.month() - 1;
      t.tm_mday = gps.date.day();
      t.tm_hour = gps.time.hour();
      t.tm_min = gps.time.minute();
      t.tm_sec = gps.time.second();
      time_t tim = mktime(&t);

      setTime(tim);
      time_set = true;
    }

    if (gps.location.isUpdated() && gps.location.isValid() && gps.altitude.isUpdated() && gps.altitude.isValid())
    {
      satellite.site(gps.location.lat(), gps.location.lng(), gps.altitude.meters());
      status.gps = true;
    }
    vTaskDelay(pdMS_TO_TICKS(TASK_GPS_DELAY));
  }
}

void Calibration_Task(void *pvParameters)
{
  uint16_t current_az = 0, current_el = 0;

  reedAz.stopCount();
  reedEl.stopCount();

  motorAz.stop();
  motorEl.stop();
  vTaskDelay(pdMS_TO_TICKS(100));

  motorAz.setDuty(M_MAX_DUTY);
  motorEl.setDuty(M_MAX_DUTY);
  motorAz.setDirection(FORWARD);
  motorEl.setDirection(FORWARD);
  vTaskDelay(pdMS_TO_TICKS(500));

  motorAz.stop();
  motorEl.stop();
  vTaskDelay(pdMS_TO_TICKS(100));

  motorAz.setDuty(M_MAX_DUTY);
  motorEl.setDuty(M_MAX_DUTY);
  motorAz.setDirection(BACKWARD);
  motorEl.setDirection(BACKWARD);
  vTaskDelay(pdMS_TO_TICKS(300));

  for (;;)
  {
    current_az = currentAz.getCurrent_mA();
    current_el = currentEl.getCurrent_mA();
    if (current_az < CURRENT_HOMING_mA && current_el < CURRENT_HOMING_mA)
    {
      motorAz.stop();
      motorEl.stop();
      vTaskDelay(pdMS_TO_TICKS(100));

      motorAz.setDuty(0);
      motorEl.setDuty(0);
      motorAz.setDirection(FORWARD);
      motorEl.setDirection(FORWARD);

      reedAz.resetCount();
      reedEl.resetCount();
      reedAz.countDirection(FORWARD);
      reedEl.countDirection(FORWARD);
      reedAz.startCount();
      reedEl.startCount();
      ESP_LOGI(TAG, "Home Reached");
      flags.home_done = true;
      Calibration_TaskHandle = NULL;
      vTaskDelete(NULL);
    }
    vTaskDelay(pdMS_TO_TICKS(TASK_HOME_CURRENT_DELAY));
  }
}

void StopMotion_Task(void *pvParameters)
{

  reedAz.countDirection(motorAz.getDirection());
  reedEl.countDirection(motorEl.getDirection());

  if (Calibration_TaskHandle != NULL)
  {
    vTaskDelete(Calibration_TaskHandle);
    Calibration_TaskHandle = NULL;
    flags.home_done = false;
  }

  if (MotionControl_TaskHandle != NULL)
  {
    vTaskDelete(MotionControl_TaskHandle);
    MotionControl_TaskHandle = NULL;
  }

  // Check actual motor stopped
  motorAz.stop();
  motorEl.stop();
  while (currentEl.getCurrent_mA() > CURRENT_HOMING_mA && currentAz.getCurrent_mA() > CURRENT_HOMING_mA)
  {
    vTaskDelay(pdMS_TO_TICKS(M_STOPPED_CHECK_INTERVAL_MS));
  }

  motorAz.setDuty(0);
  motorEl.setDuty(0);
  motorAz.setDirection(FORWARD);
  motorEl.setDirection(FORWARD);
  reedAz.countDirection(FORWARD);
  reedEl.countDirection(FORWARD);
  flags.stop_done = true;
  StopMotion_TaskHandle = NULL;
  vTaskDelete(NULL);
}

// TODO: Ignore motor peak current at start up
void CurrentMonitor_Task(void *pvParameters)
{
  for (;;)
  {
    float current_az = currentAz.getCurrent_mA();
    float current_el = currentEl.getCurrent_mA();

    if (current_az > CURRENT_AZIMUTH_MAX_mA)
    {
      ESP_LOGW(TAG, "Azimuth Motor Overcurrent: %.2f mA", current_az);
      status.tracking = false;
      status.error = TRACKER_ERROR_OVERCURRENT_AZ;
    }
    if (current_el > CURRENT_ELEVATION_MAX_mA)
    {
      ESP_LOGW(TAG, "Elevation Motor Overcurrent: %.2f mA", current_el);
      status.tracking = false;
      status.error = TRACKER_ERROR_OVERCURRENT_EL;
    }

    vTaskDelay(pdMS_TO_TICKS(TASK_CURRENT_MONITOR_DELAY));
  }
}

void telemetry_Task(void *pvParameters)
{
  for (;;)
  {
    serverHandler.sendTelemetry();
    vTaskDelay(pdMS_TO_TICKS(TASK_TELEMETRY_DELAY));
  }
}

void IRAM_ATTR reedAz_event_handler(void *arg)
{
  status.tracking = false;
  status.error = TRACKER_ERROR_SOFT_ENDSTOP;
  // TODO Software endstops
}

void IRAM_ATTR reedEl_event_handler(void *arg)
{
  status.tracking = false;
  status.error = TRACKER_ERROR_SOFT_ENDSTOP;
  // TODO Software endstops
}

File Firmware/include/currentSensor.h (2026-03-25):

/**
 * @file current.h
 * @brief Definition of the CurrentSensor class for current measurement using the ESP32's ADC.
 *
 * This module allows measuring the current consumed by a motor
 * using the internal Analog-to-Digital Converter (ADC) of the ESP32.
 * The measurement is performed through a **shunt resistor** and
 * **operational amplifiers (op-amps)** that condition the signal.
 *
 */

#ifndef CURRENT_H
#define CURRENT_H

#include "esp_adc_cal.h"
#include "driver/adc.h"
#include "driver/gpio.h"
#include "esp_err.h"
#include "configurations.h"

/** * @name ADC Configuration
 * Constants for configuring the ESP32's ADC unit.
 * @{
 */
/** @brief ADC attenuation (range of 100 mV to 950 mV) for high precision. */
#define ADC_ATTEN           ADC_ATTEN_DB_0
/** @brief ADC unit used (ADC1). */
#define ADC_NUM_1           ADC_UNIT_1
/** @brief ADC resolution (12 bits = 4096 levels). */
#define ADC_WIDTH           ADC_WIDTH_BIT_12
/** @brief Default value of the internal ADC reference voltage (in mV). */
#define ADC_DEFAULT_VREF    1100
/** @} */

/** * @name Current Measurement Constants
 * Constants specific to the current measurement circuit.
 * @{
 */
/** @brief Shunt resistor value in Ohms. */
#define DEFAULT_SHUNT_VALUE_OHM 0.22f
/** @brief Operational amplifier gain. */
#define DEFAULT_OPAMP_GAIN      2.12f
/** @} */

/**
 * @class CurrentSensor
 * @brief Class for current reading using an ESP32 ADC channel.
 *
 * This class configures an ADC channel, calibrates the conversion to millivolts (mV),
 * and calculates the current in milliamperes (mA), considering the shunt resistor
 * and the amplifier gain.
 */
class CurrentSensor
{
private:
    adc1_channel_t channel;                  /**< @brief Configured ADC channel for measurement. */
    esp_adc_cal_characteristics_t adc_chars; /**< @brief ADC calibration characteristics structure. */
    uint32_t offset_mV = 0;                  /**< @brief Voltage offset (in mV) measured under zero current condition. */
    float shunt_ohm = DEFAULT_SHUNT_VALUE_OHM; /**< @brief Shunt resistor value in Ohms. */
    float opamp_gain = DEFAULT_OPAMP_GAIN;   /**< @brief Operational amplifier gain. */

    /**
     * @brief Performs multiple ADC readings and returns the average.
     * * Used to reduce electrical noise in the analog signal.
     * @param samples Number of samples to collect.
     * @return Averaged raw ADC value.
     */
    uint32_t multisample(uint8_t samples);

public:
    /**
     * @brief Constructor for the CurrentSensor class.
     *
     * Configures the ADC width and attenuation, and performs characterization
     * to obtain the voltage conversion curve.
     *
     * @param channel The ADC1 channel to be used for the measurement.
     */
    CurrentSensor(adc1_channel_t channel);

    /**
     * @brief Gets the measured current in milliamperes (mA).
     *
     * Reads the analog value, applies calibration and offset, and calculates the current
     * using Ohm's Law and the amplifier gain:
     * * @f[ I_{mA} = \frac{V_{Shunt, mV}}{G \cdot R_{Shunt, \Omega}} @f]
     *
     * @return Measured current in milliamperes (mA).
     */
    float getCurrent_mA();

    /**
     * @brief Gets the shunt resistor voltage in millivolts.
     *
     * Takes an average of raw ADC readings, converts it to voltage using 
     * calibration, and subtracts the calibrated offset.
     *
     * @return Shunt voltage in millivolts (mV).
     */
    uint32_t getShuntVoltage_mV();

    /**
     * @brief Calibrates the sensor's voltage offset.
     *
     * Measures the voltage of the ADC pin when the input current is zero (0)
     * to establish the `offset_mV` value. 
     * @warning Must be called with no current applied to the motor.
     */
    void calibrateOffset();

    /**
     * @brief Gets the calibrated voltage offset value.
     * @return The offset value in millivolts (mV).
     */
    uint32_t getOffset_mV();

    /**
     * @brief Sets a new shunt resistor value.
     * @param shunt_ohm New shunt resistor value in Ohms.
     */
    void setShuntValue(float shunt_ohm);
    
    /**
     * @brief Sets a new operational amplifier gain.
     * @param gain New operational amplifier gain.
     */
    void setOpAmpGain(float gain);
};

#endif // CURRENT_H

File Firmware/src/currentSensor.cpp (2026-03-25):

#include "currentSensor.h"

CurrentSensor::CurrentSensor(adc1_channel_t channel)
{
    this->channel = channel;
    adc1_config_width(ADC_WIDTH);
    adc1_config_channel_atten(channel, ADC_ATTEN);
    esp_adc_cal_characterize(ADC_NUM_1, ADC_ATTEN, ADC_WIDTH, ADC_DEFAULT_VREF, &adc_chars);
}

uint32_t CurrentSensor::getShuntVoltage_mV()
{
    int32_t voltage_mV = esp_adc_cal_raw_to_voltage(this->multisample(ADC_MEASURE_SAMPLES), &adc_chars) - this->offset_mV;
    return (voltage_mV < 0)? 0 : voltage_mV;
}

float CurrentSensor::getCurrent_mA()
{
    return this->getShuntVoltage_mV() / (float)(this->opamp_gain * this->shunt_ohm);
}

uint32_t CurrentSensor::getOffset_mV()
{
    return this->offset_mV;
}

void CurrentSensor::setOpAmpGain(float gain)
{
    this->opamp_gain = gain;
}

void CurrentSensor::setShuntValue(float shunt_ohm)
{
    this->shunt_ohm = shunt_ohm;
}

uint32_t CurrentSensor::multisample(uint8_t samples)
{
    uint32_t sum = 0;
    for (uint8_t i = 0; i < samples; i++)
    {
        sum += adc1_get_raw(channel);
    }
    return sum / samples;
}

void CurrentSensor::calibrateOffset()
{
    this->offset_mV = esp_adc_cal_raw_to_voltage(this->multisample(ADC_MEASURE_SAMPLES), &adc_chars);
}

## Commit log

2025-10-31 HTTP Server Done, mDNS Done, Drivers Done.
2025-10-31 Current firmware
2025-11-14 new file: include/configurations.h Pin & Configs new file: include/currentSensor.h Added Offset calib modified: include/motorDriver.h Added NonLinelity
    [configurations.h]
2025-11-16 modified: include/configurations.h General configurations modified: src/main.cpp Interpolation & RTC internal added modified: src/pid.cpp Functional changes modified: src/server.cpp structure improve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
    [configurations.h]
2025-11-17 modified: data/index.html Moddified IU
    [configurations.h]
2025-11-21 modified: include/configurations.h Added more Control definitions modified: include/utils.h Added non linearity functions modified: src/main.cpp Implemented Control/Movement algorithm modified: src/u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
    [configurations.h]
2025-12-08 new file: include/PI_Controller.h Added discrete PI Controller modified: include/configurations.h PWM freq & Signal Adaptation changes
    [configurations.h]
2025-12-10 minor changes
    [configurations.h]
2025-12-15 Fixed minor bugs
    [configurations.h]
2026-02-07 modified: data/index.html Added Graphs and styling modified: include/PI_Controller.h Low Pass on Input modified: include/configurations.h Added Frequency of Reed Switches modified: src/PI_Controller.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
    [configurations.h]
2026-02-11 modified: src/main.cpp fix minor bug in main loop
    [configurations.h]
2026-02-12 modified: include/PI_Controller.h Added reset modified: src/PI_Controller.cpp Added reset modified: src/main.cpp New efficient Control
    [main.cpp]
2026-02-12 modified: include/configurations.h updated coeff
    [configurations.h]
2026-02-17 modified: include/configurations.h constants and configurations
    [configurations.h]
2026-02-17 Refactor: move firmware files to a dedicated 'Firmware' directory
    [configurations.h]
2026-02-18 Archivos, piezas, documentación...
    [ActLineal1.SLDPRT, ActLineal2.SLDPRT, ActRotacional.SLDPRT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]
2026-02-18 modified: Firmware/data/index.html Added visibility modified: Firmware/src/main.cpp Added prediction of horizon crossing new file: "Hardware/Funci\303\263nTransferencia.xlsx"
    [FunciónTransferencia.xlsx]
2026-02-25 modified: Firmware/data/index.html Fixed Graph bugs new file: Hardware/Dimensiones.png Mount Parameter Dimensions
    [configurations.h]
2026-03-04 modified: Firmware/data/index.html change Telemetry w/SSE modified: Firmware/include/server.h change Telemetry w/SSE modified: Firmware/src/main.cpp Added next pass prediction fnc modified: Firmware/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
    [configurations.h]
2026-03-06 modified: Firmware/src/main.cpp Deleted reed filter & Smoother Control
    [FunciónTransferencia.xlsx, configurations.h]
2026-03-07 Added Doxy Doc & Minified HTML
    [configurations.h]
2026-03-09 modified: Firmware/src/main.cpp Check Actual motor stop modified: Web_Interface/index.html Add auto-reconnect
    [configurations.h]
2026-03-25 modified: Firmware/include/currentSensor.h modified: Firmware/include/server.h modified: Firmware/src/currentSensor.cpp modified: Firmware/src/main.cpp
    [configurations.h]
2026-03-25 modified: Firmware/src/main.cpp
    [configurations.h]
2026-04-06 modified: Firmware/data/index.html
    [compas.SLDPRT, compas.STL, compas2.SLDPRT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]
